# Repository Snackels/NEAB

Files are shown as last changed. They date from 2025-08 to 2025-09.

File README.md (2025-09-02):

# **Documentation for WRO Future Engineer 2025** 
by Team **YBR-NEAB**



<p align="center">
  
</p>
<p align="center">
<b>By Yothinburana School Robot Club</b>
</p>
<br><br><br><br>

### This Github repository contains:
- [About our team](#about-our-team)
- [Engineering Consideration](#engineering-consideration)
- [Chassis Design](#chassis-design)
- [Hardware Information](#hardware-information)
- [ROS 2 Humble Explanation](#ros-2-humble-explanation)
- [Raspberry Pi Program](#raspberry-pi-program)
- [Arduino Program](#arduino-program)
- [Contact Us!](#contact)

# **About our team.**
<p align="center">
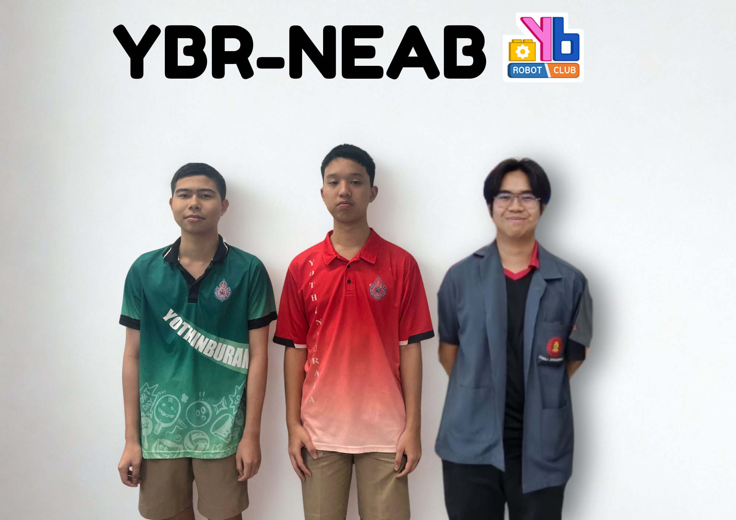
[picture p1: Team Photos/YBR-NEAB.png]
  
</p>
Our team consists of three members, each assigned a different role:

1. Vichaiwat Koonsap – I am responsible for gathering data for our team members and taking detailed notes, which are then compiled into this documentation. I'm the on the middle.
2. Norrapat Kesthong – Norrapat is responsible for designing and building our robot. He's on the right side.
3. Vorawet Narkglom – Vorawet is the programmer who coded the robot. He stands on the left side.

# **Engineering Consideration.**

During the design process of our robot, we faced several engineering challenges, particularly in translating real-world measurements into our 3D modeling software. After printing, we frequently encountered issues with small features—for example, a M3 screw thread could not be printed accurately caused by 3d printer's nozzle size, resulting in undersized holes. This showed the importance of accounting for 3D printer limitations during the design stage. Paying close attention to these details helps minimize unnecessary redesigns and reprints.

Another key learning was the importance of incorporating a differential system. At first, we placed gears of equal size next to each other, but this setup proved ineffective. By integrating a differential, the wheels were able to rotate at different speeds—an essential factor for smooth turning and overall robot performance.

The robot chassis was modeled in Fusion 360 and manufactured using FDM 3D printing. This approach provided durability, lightweight construction, and effective protection for the onboard hardware. The design was fully customized by our mechanic to meet the specific needs of our robot.

# Chassis Design
## 3D Printer and Filament
### Bambu Lab P1S Combo
<p align="center">
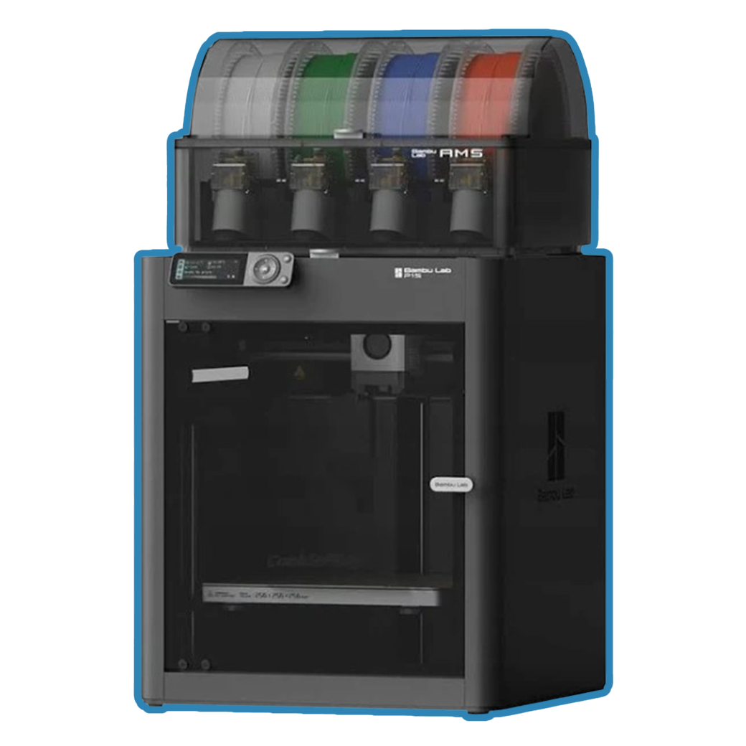
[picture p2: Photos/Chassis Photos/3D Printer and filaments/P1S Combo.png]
  
</p>
This is our 3D printer, which we use to produce both prototypes and the final robot chassis. It is capable of high-speed printing without compromising quality or risking failure. The printer features a fully enclosed chamber, allowing safe printing of high-temperature or hazardous materials such as ABS and ASA. It is one of Bambu Lab’s best-selling models.

Additionally, it comes with an Automated Material System (AMS), enabling the printer to handle up to four different materials—whether the same or different types of plastic. The AMS also includes an Auto Reload function, allowing us to print overnight without worrying about filament running out.
#### Specification
| Feature | Details |
|---|---|
| **Model** | P1S Combo |
| **Build Volume** | 256 × 256 × 256 mm³ |
| **Print Speed** | Up to 500 mm/s |
| **Acceleration** | Up to 20,000 mm/s² |
| **Extruder Type** | Direct Drive |
| **Nozzle Type** | Stainless Steel (upgradeable to hardened steel) |
| **Hotend Max Temp** | 280°C (supports high-temp filaments with upgraded nozzle) |
| **Heatbed Max Temp** | 100°C |
| **Enclosure** | Fully enclosed with carbon filter and fans |
| **Cooling System** | Auxiliary part cooling fan, chamber regulator fan, control board fan |
| **AMS Compatibility** | Yes (supports up to 16-color multi-material printing) |
| **Connectivity** | Wi-Fi, USB, Bambu-Bus |
| **Display** | 2.7-inch 192×64 screen |
| **Software** | Bambu Studio (supports Cura, PrusaSlicer, SuperSlicer) |
| **Camera** | Built-in for remote monitoring and time-lapse |
| **Dimensions (WxDxH)** | 389 × 389 × 458 mm³ |
| **Weight** | 9.5 kg |
| **Power Input** | 100–240 VAC, 50/60 Hz |
| **Max Power Consumption** | 1000 W @ 220V, 350 W @ 110V |

---

### Polylactic Acid or PLA 
<p align="center">
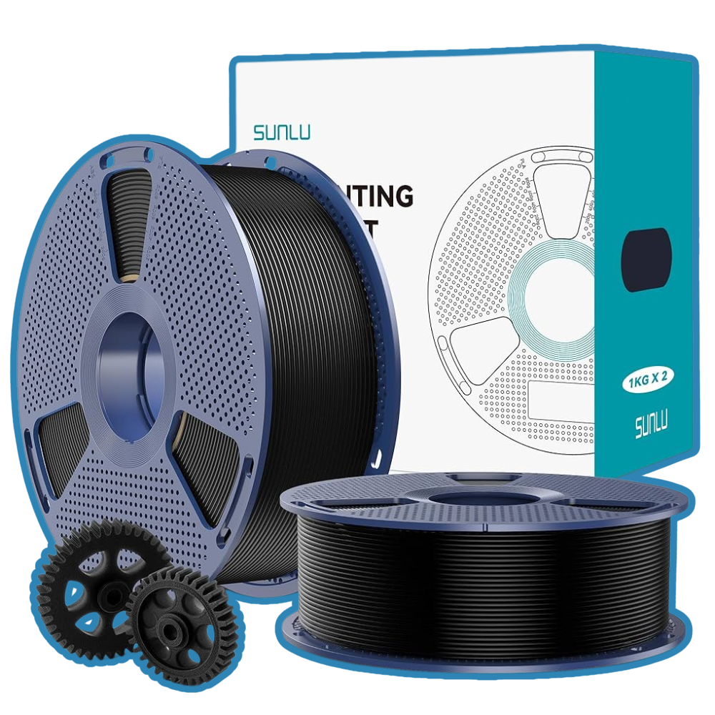
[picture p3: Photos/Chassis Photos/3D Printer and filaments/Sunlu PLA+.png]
  
</p>
PLA is the most common filament used in 3D printing. It is easy to print, produces minimal stringing, and requires relatively low printing temperatures. However, it also has some drawbacks: it cannot withstand high heat and is more brittle compared to other materials. Because of this, we use PLA for thin parts that need to remain lightweight while still providing support without bending.

For our robot, we selected **Sunlu PLA+ 2.0**, an enhanced version of standard PLA. This material is stronger, lighter, and more flexible, giving us the benefits of PLA while improving durability and performance.

### Polyethylene Terephthalate Glycol or PETG
<p align="center">
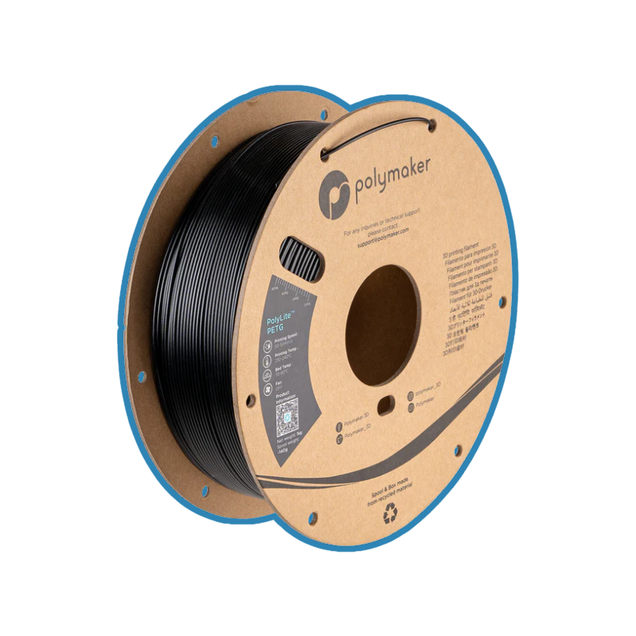
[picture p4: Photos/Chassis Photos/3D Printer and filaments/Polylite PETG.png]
  
</p> 
PETG is another popular 3D printing filament, valued for its flexibility, strength, chemical resistance, and ability to withstand higher temperatures than PLA. Its main drawbacks are increased stringing and a slightly rougher surface finish.

Because PETG is highly impact-resistant, we use it for components that are more likely to experience collisions, ensuring the robot remains intact even after repeated impacts.

For our robot, we selected **Polymaker PolyLite PETG**. Polymaker is a trusted brand known for its consistency and reliability, with minimal defects. This PETG is particularly user-friendly, offering printability close to that of PLA while maintaining the toughness needed for demanding parts.

---

## Printed Robot Chassis
[All the 3D printable models can be found here](https://github.com/Snackels/NEAB/tree/main/3D%20models).
### Lower Base
<p align="center">
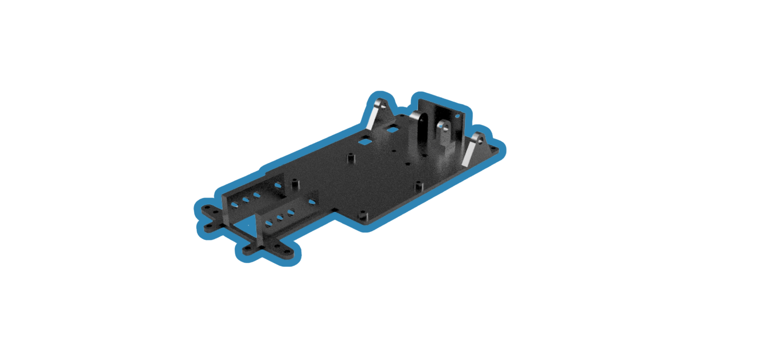
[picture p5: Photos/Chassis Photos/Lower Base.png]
  
</p>
The lower base serves as the foundation of our robot, supporting nearly all essential components: the controller, motors, steering servo, light sensors, buck converter, and differential.  
 
When designing this part, precise measurements were critical to ensure a proper fit for each component. In our robot, we uses a **LEGO TECHNIC** parts like axle, differential, and gear to ensure that those part would not break during our sessions.

To secure the LEGO axle, we designed support poles at the back of the base to hold it firmly in place. With this design, it allows the robot to reach it's full potential.

### Upper Base
<p align="center">
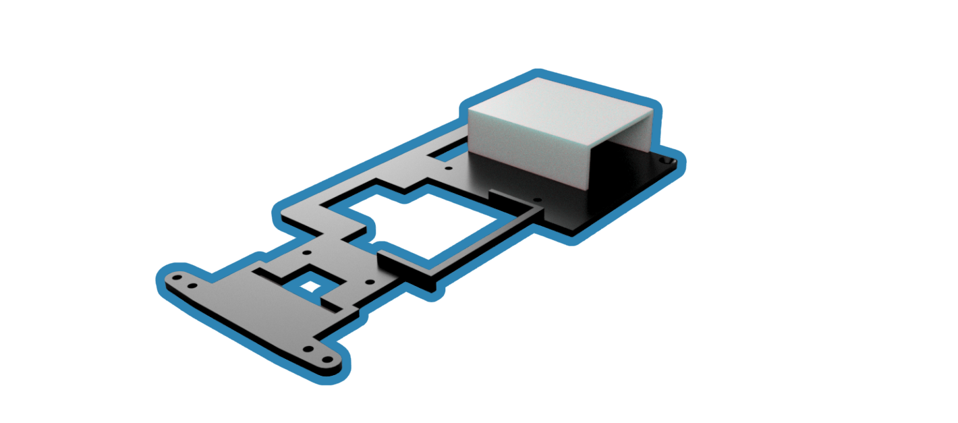
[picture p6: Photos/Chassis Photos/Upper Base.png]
  
</p>
The upper base is positioned 3 cm above the lower base and is designed to hold the remaining components while providing additional stability to the robot.  

To ensure a clean and seamless build, we applied the **counterbore technique** so that screws do not interfere with the lower section. This approach allowed us to hide the screws neatly, giving the chassis a screwless appearance.  

Additionally, the upper base includes a **battery slot** at the back, ensuring secure placement and easy accessibility during operation.

### Arduino Nano Riser
<p align="center">
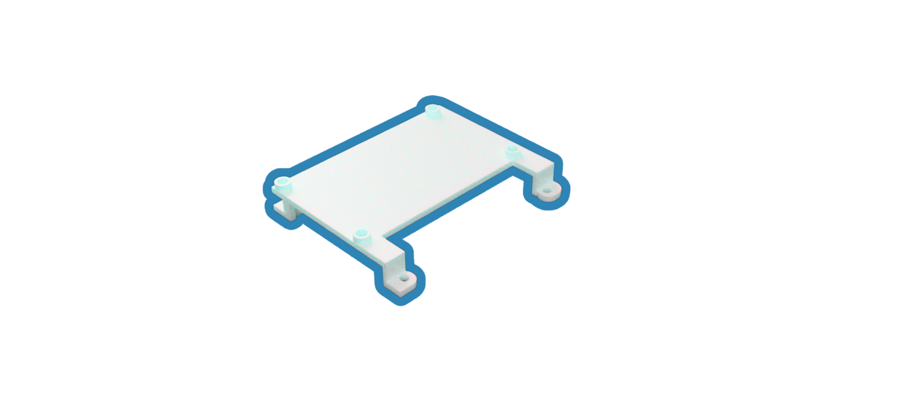
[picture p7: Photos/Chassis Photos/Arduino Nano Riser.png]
  
</p>
Since we are using the Arduino Nano, we needed to find an ideal place to mount it. The perfect location is right on top of the Raspberry Pi, allowing both boards to stay compact and organized. To achieve this, we designed the setup to use the same M2.5 screws that secure the Raspberry Pi. We also carefully accounted for the position of the GPIO pins and all necessary wiring, ensuring that everything fits neatly without interfering with connections.

### LiDAR Holder
<p align="center">
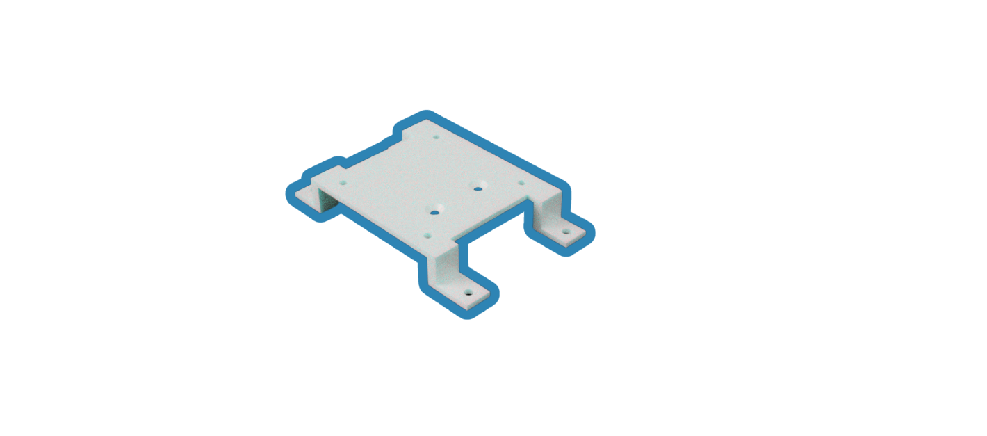
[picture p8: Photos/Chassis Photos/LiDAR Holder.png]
  
</p>
The LiDAR holder is mounted on top of the upper base to keep the LiDAR elevated above other components. This prevents the sensor from mistakenly detecting parts of the robot itself.  

The holder also included a **slot for the gyro sensor**, positioned directly beneath the LiDAR. This compact arrangement minimizes the overall robot size while ensuring that the LiDAR remains within the **10 cm height limit** to avoid detecting over the wall.  

### Camera mount
<p align="center">
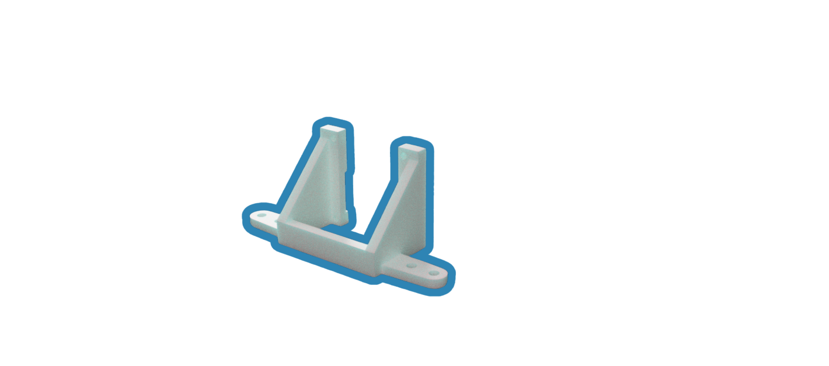
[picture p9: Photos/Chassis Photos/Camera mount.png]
  
</p>
This component serves as a **stand for the camera** and includes protective covers for both the front and top.  

The design serves two key purposes:  
1. **Protection** – In case of collisions with walls, the front cover acts as a guard to protect the camera lens from damage.  
2. **Vision Control** – The top cover blocks external light and distractions, ensuring the camera only captures the track area.  

This combination enhances both the durability and reliability of the vision system during sessions.  

### Motor Bracket
<p align="center">
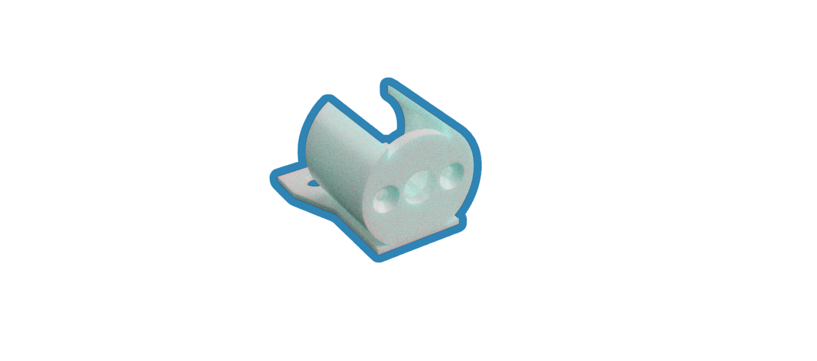
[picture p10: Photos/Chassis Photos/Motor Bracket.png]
  
</p>
It holds the motor with the lower base. This design offer us a small, effective, and strong bracket. With 3 screw holes for attaching it to the base and 2 screw holes for attaching it to motor. This part also uses the Counterbore technique.

### Gear Adapter
<p align="center">
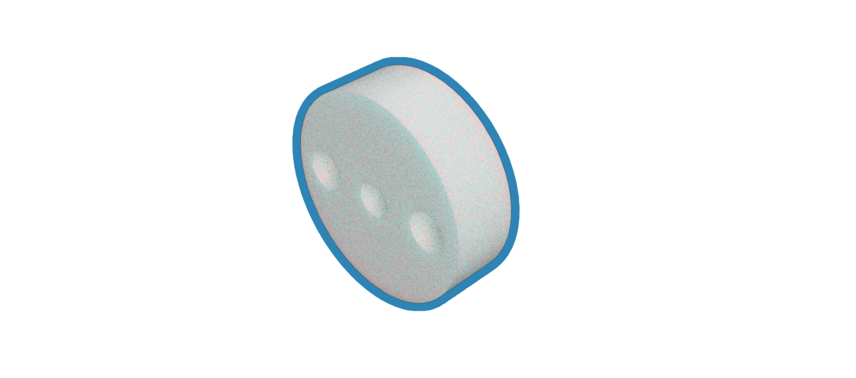
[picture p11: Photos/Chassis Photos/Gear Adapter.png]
  
</p>
The gear we used was from **LEGO Technic**. Meaning that we can't attach it directly to the motor. We designed this part to place it on motor's rotating axle. Then, we added two LEGO pins to attach it to the gear.

### Step-Down Case
<p align="center">
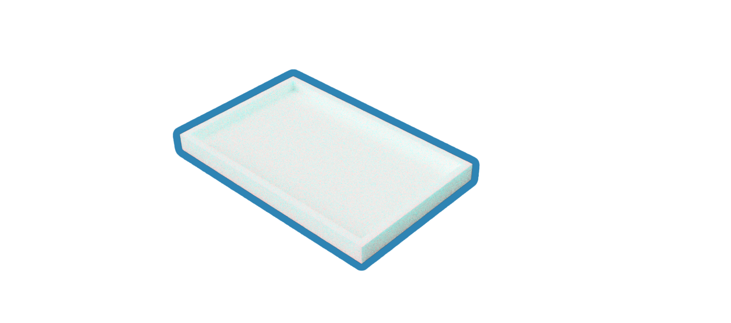
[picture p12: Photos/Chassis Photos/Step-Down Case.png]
  
</p>
The buck converter comes with a lot of pin under it. This was caused by soldering. This case was made to make sure that the bottom stays flat and avoid current leakage.

### Steering Module
<p align="center">
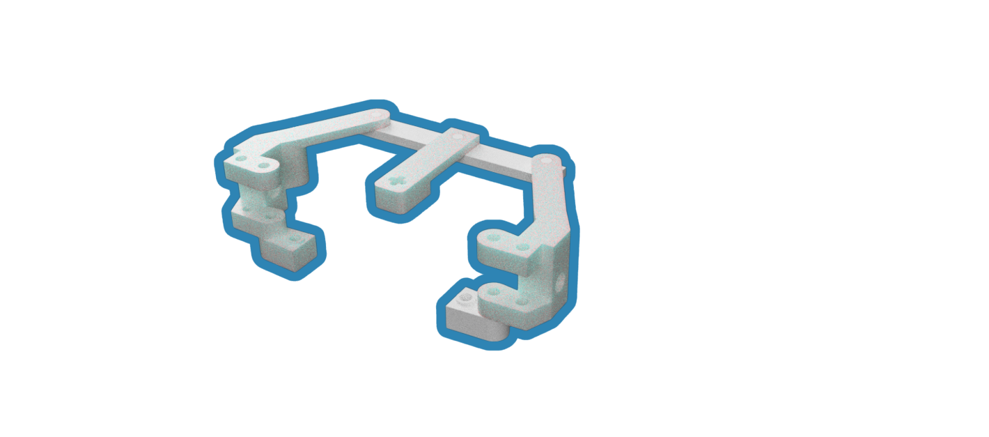
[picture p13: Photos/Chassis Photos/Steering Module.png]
  
</p>
It consists of three main components: the servo link, main connector, and wheel bracket. When our mechanic designed this part, careful consideration was given to the steering angle. We applied the Ackermann Steering Principle, a system developed to achieve tighter and more efficient turns. With this method, the inner wheel turns at a sharper angle than the outer wheel—similar to the steering system used in Formula 1 cars. We also ensured that, during turns, the wheels would not collide with the robot’s body.

---

## LEGO Technic Parts
### Differential
<p align="center">
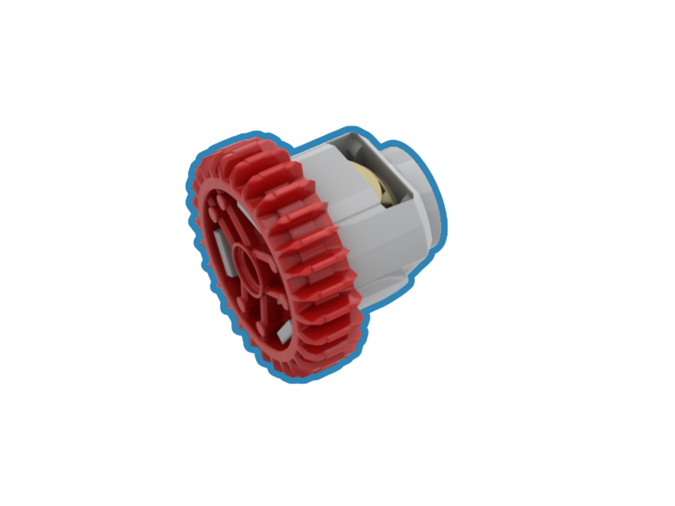
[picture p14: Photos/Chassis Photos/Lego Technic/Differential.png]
  
</p>
This differential includes a 28-tooth double bevel gear, identical to the one used with our motor. Inside, it contains five small gears that allow the opposite wheel to rotate freely. This mechanism ensures that both wheels rotate at the correct speed, even when the robot is turning.

### Gear
<p align="center">
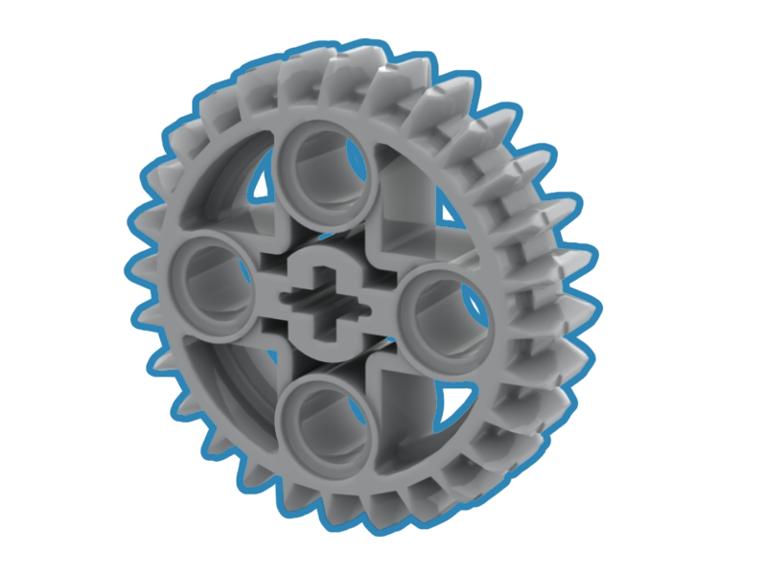
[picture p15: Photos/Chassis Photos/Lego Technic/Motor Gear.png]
  
</p>
We selected a 28-tooth double bevel gear to prevent the robot from losing speed or torque. It is made of ABS plastic, providing durability, and matches the size of the differential.

### Wheel: 43.2 * 22
<p align="center">
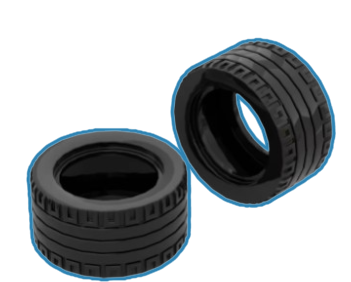
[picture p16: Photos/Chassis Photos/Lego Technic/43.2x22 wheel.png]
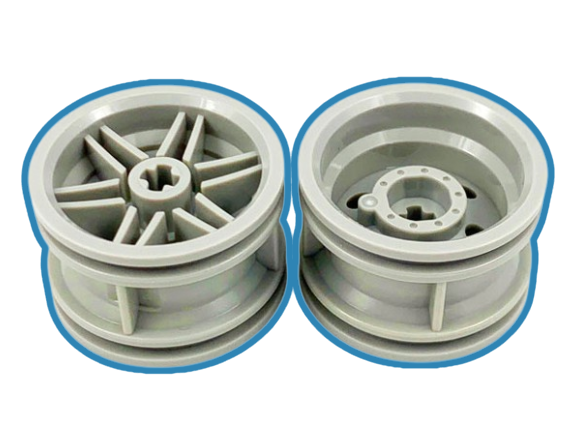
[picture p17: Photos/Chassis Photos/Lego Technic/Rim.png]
  
</p>
The wheel is a crucial component of our robot and comes in various sizes and shapes. We selected this size for its ability to maintain grip on the surface during high-speed turns. Its 43.2 diameter also makes the robot easy to control.

### Pin
<p align="center">
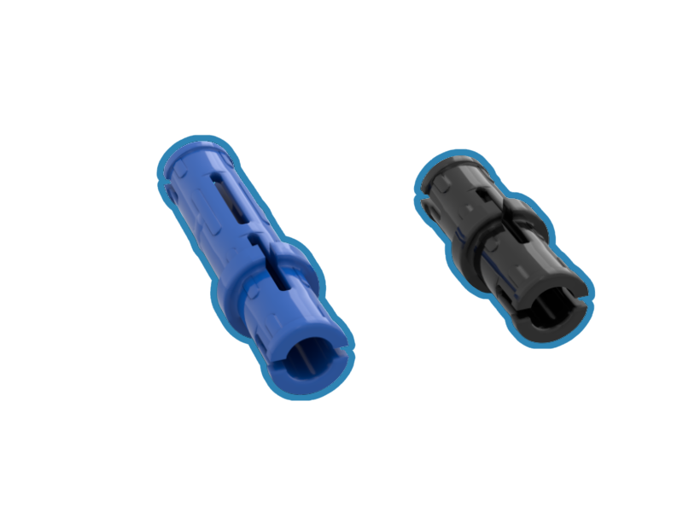
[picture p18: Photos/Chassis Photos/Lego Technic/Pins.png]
  
</p>
These pins are used to secure the servo to the robot. They act as a lock, ensuring the servo stays firmly in place.

### Axle
<p align="center">
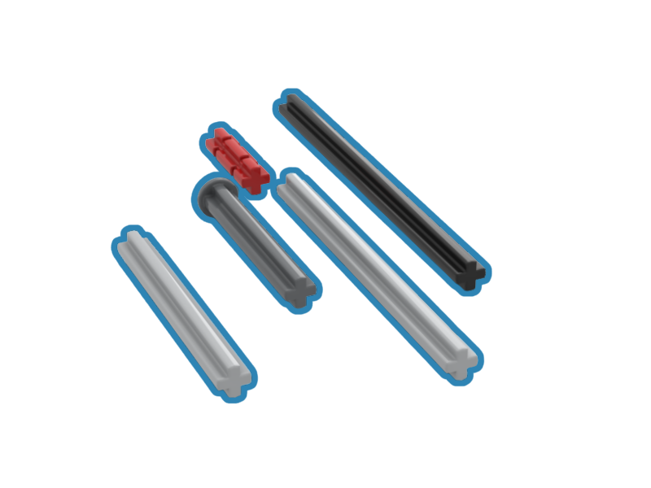
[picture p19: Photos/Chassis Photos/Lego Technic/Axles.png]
  
</p>
Axles connect the wheels to the robot. We designed a 5.1 mm hole for the axle, allowing it to sit securely while still rotating freely.

### Half Bush
<p align="center">
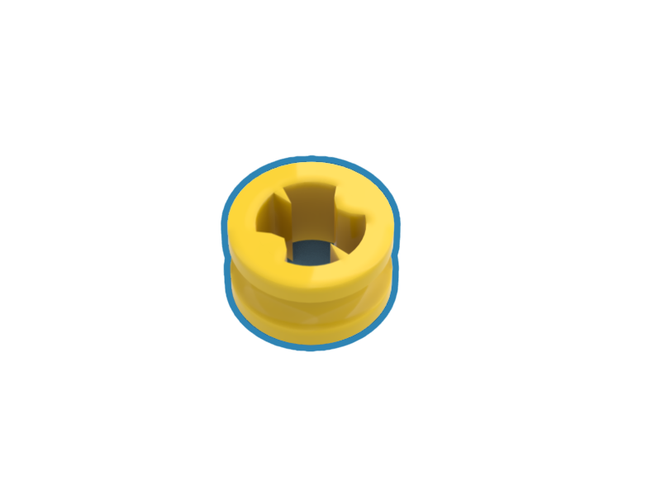
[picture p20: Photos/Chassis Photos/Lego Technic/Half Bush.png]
  
</p>
This component creates space between the wheel and the robot, ensuring that the wheels can rotate freely without being obstructed during operation.

---

## Additional
### Screws
Screws come in various sizes. We designed our robot primarily around M3 screws, as they are the most common in robotics. In some cases, such as mounting the Raspberry Pi or LiDAR, M2.5 screws are required. For our build, we mainly use countersunk screws. To accommodate them, we chamfered the M3 screw holes by 1.8 mm, creating the perfect countersunk fit that allows the screws to sit flush and remain neatly hidden.

<p align="center">
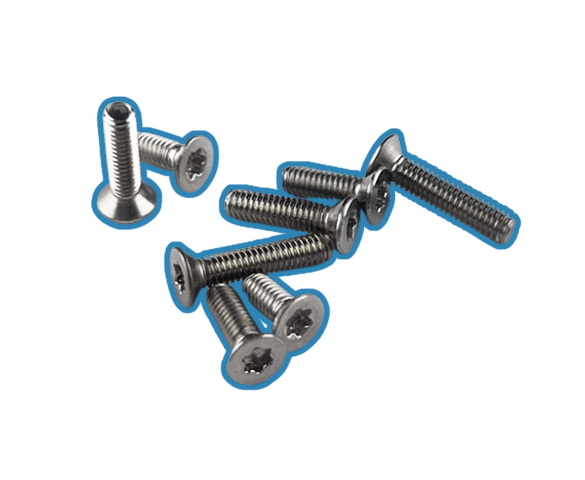
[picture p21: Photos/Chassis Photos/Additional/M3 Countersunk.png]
  
  <br>
  <b>M3 Countersunk Screws</b>
</p>

<p align="center">
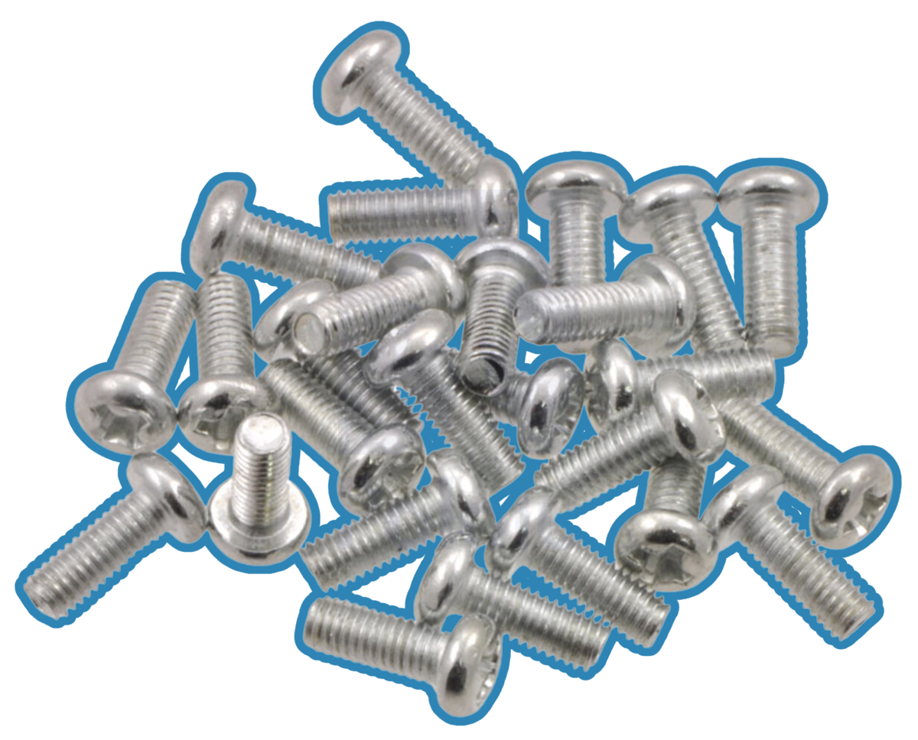
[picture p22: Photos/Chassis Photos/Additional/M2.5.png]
  
  <br>
  <b>M2.5 Screws</b>
</p>

---

### PCB Support Post
<p align="center">
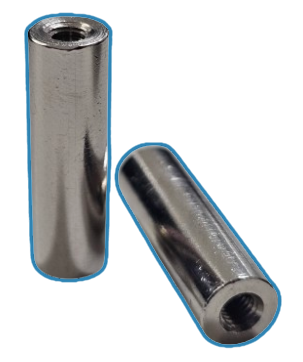
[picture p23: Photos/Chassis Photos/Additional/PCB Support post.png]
  
</p>
The support posts connect the first and second floors of the robot. They enhance stability, ensuring that the LiDAR and camera remain steady during operation.

## Design References
### Counterbore Technique
<p align="center">
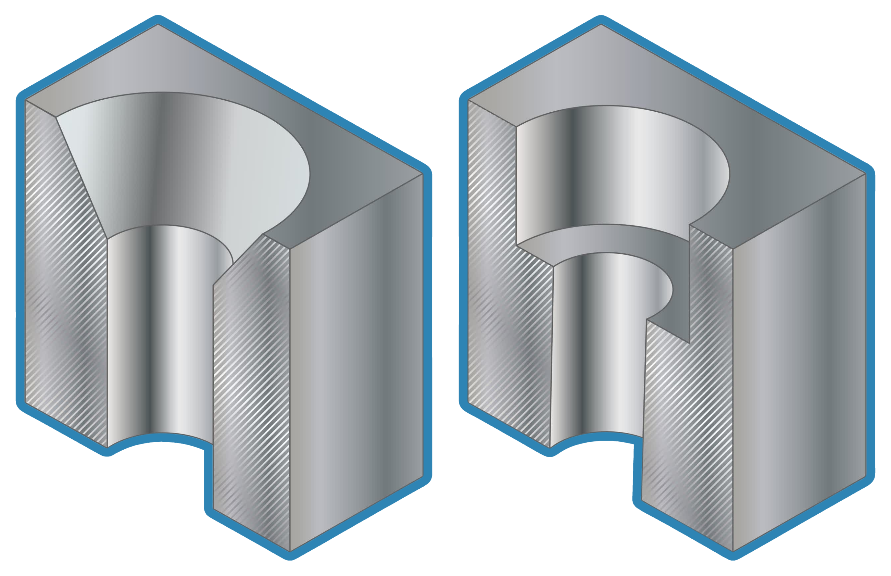
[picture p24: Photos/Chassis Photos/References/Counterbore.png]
  
</p>
Counterbore and countersunk are two techniques used to make screws sit flush with a surface. A countersunk hole has an angled top, allowing cone-shaped screws to fit neatly inside and create a smooth finish, while a counterbore hole has a flat, widened top so cylindrical screw heads can sit below the surface. In our robot, we use these methods to merge the screw into the structure by chamfering 1.8 mm into the screw hole or creating a 4 mm wide hole with a 2 mm depth. This not only saves space but also gives the robot a cleaner and more professional look.

### Ackerman Steering
<p align="center">
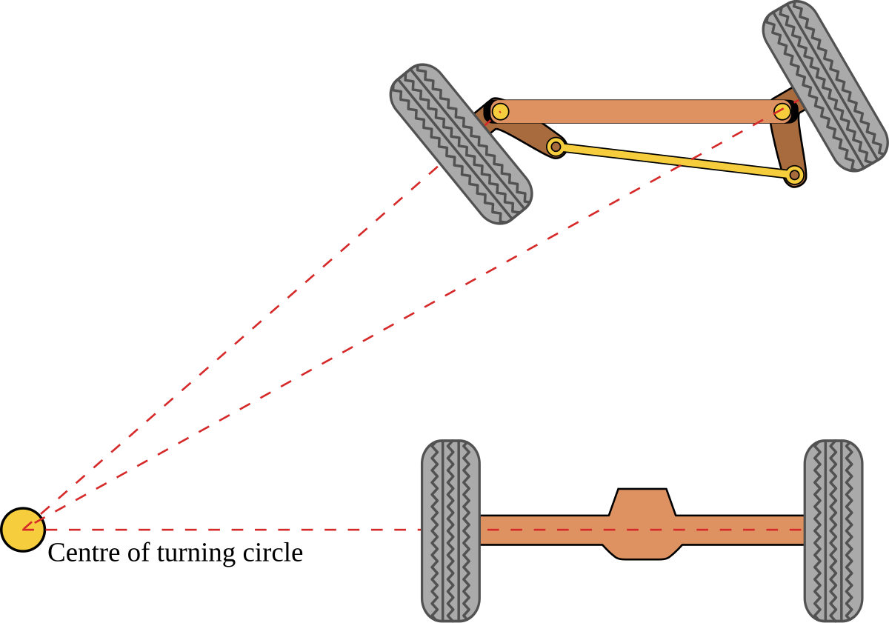
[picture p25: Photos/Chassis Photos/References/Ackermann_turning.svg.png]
  
</p>
Ackermann steering is a method where the inner wheel turns sharper than the outer wheel when the robot turns. This matches the natural path of the wheels, preventing them from sliding against the ground. It makes the robot easier to control, gives it a tighter turning radius, and reduces friction—just like in real cars and F1 racing.

## Printing Process
To print this robot, we first use a slicer to generate the ****G-code** for the 3D printer. In our case, we use **Bambu Studio**. A slicer lets us set up a **print profile**, which defines whether the part will be strong, lightweight, or have a smooth surface. Once the profile is set, we check for **overhangs** — parts of the model that **“float”** without support. While printers can handle small overhangs, larger ones require supports. Supports are temporary structures that hold the object during printing and can be removed afterward. There are two main types: **normal supports** and **tree supports**, with tree supports being the most popular because they use less filament and print faster. After preparing everything, we start the print.

Here’s a timelapse of the printing process for some of our parts:
| Accessories Timelapse | Lower Chassis Timelapse |
|---|---|
|  |  |

### Post-Printing Process
After a print is complete, some defects may appear. The most common one is **stringing**, which can be removed by applying gentle heat with a lighter or heat gun. Stringing is usually caused by **moist filament**, especially with PETG. To prevent this, use a filament dryer to remove excess moisture.

Another common issue is an **uneven or rough surface**. This can result from blobbing, an unlevel print bed, or low-quality filament. The surface can be improved by sanding with fine sandpaper.  

Lastly, there’s **support and brim removal**. Supports are needed for complex prints, while brims improve bed adhesion. However, they often leave rough edges, which can be cleaned up with the right tools.

---

#### Essential 3D Printing Tools

- **Plier**  
<p align="center">
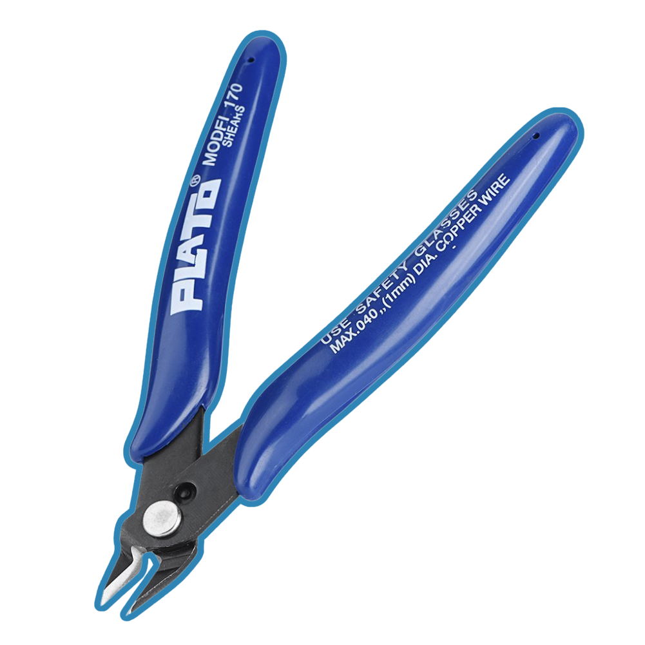
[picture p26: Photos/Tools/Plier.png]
  
</p>  
Used for removing supports and trimming away unwanted parts of the print.

---

- **Glue Stick**  
<p align="center">
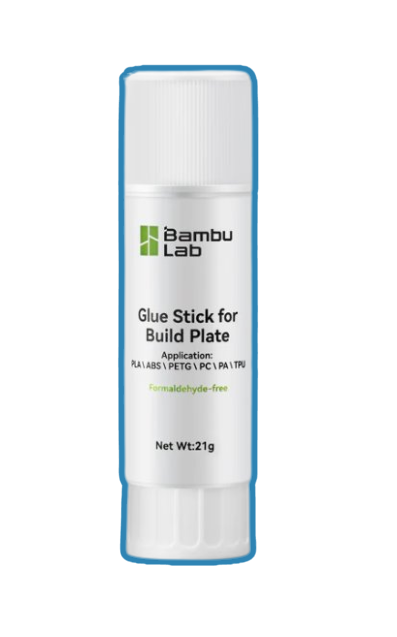
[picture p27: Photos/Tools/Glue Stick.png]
  
</p>  
Applied to the print bed as a **release agent**—not to increase stickiness, but to make parts easier to remove once printing is finished.

---

- **Lighter or Heat Gun**  
<p align="center">
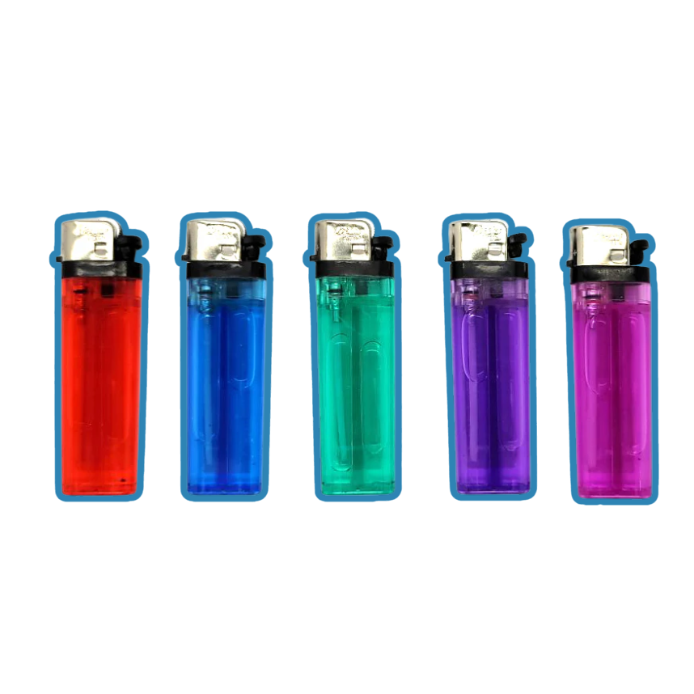
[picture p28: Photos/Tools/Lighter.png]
  
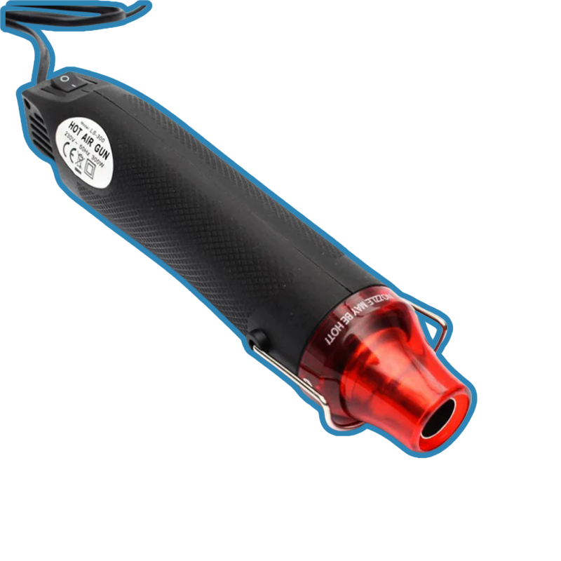
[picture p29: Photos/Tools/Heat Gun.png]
  
</p>

<p align="center">
  Lighter &nbsp;&nbsp;&nbsp;&nbsp;|&nbsp;&nbsp;&nbsp;&nbsp; Heat Gun
</p>

Essential for removing stringing. In some cases, heat can also soften the plastic, making it easier to reshape.

---

- **Deburring Tool**  
<p align="center">
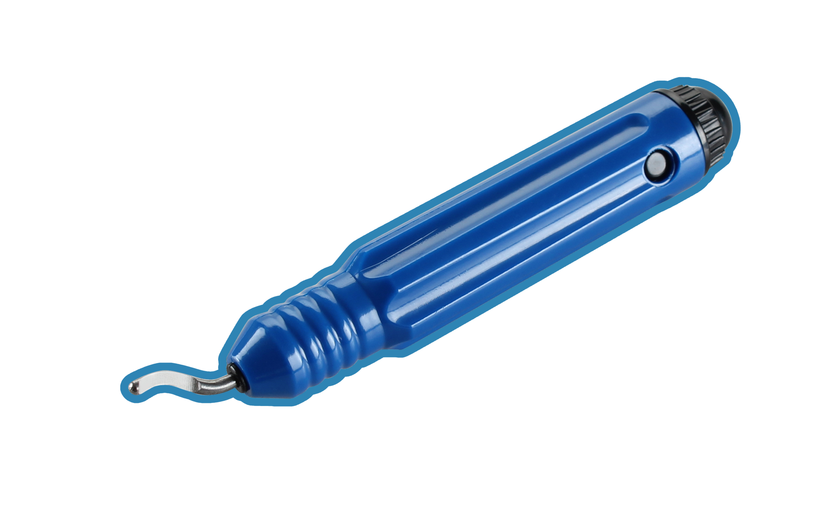
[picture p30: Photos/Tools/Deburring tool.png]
  
</p>  
Designed to remove brims. Brims help parts stick to the bed, but sometimes they bond too well, leaving rough edges. A deburring tool makes cleanup much easier.

---

- **Sandpaper**  
<p align="center">
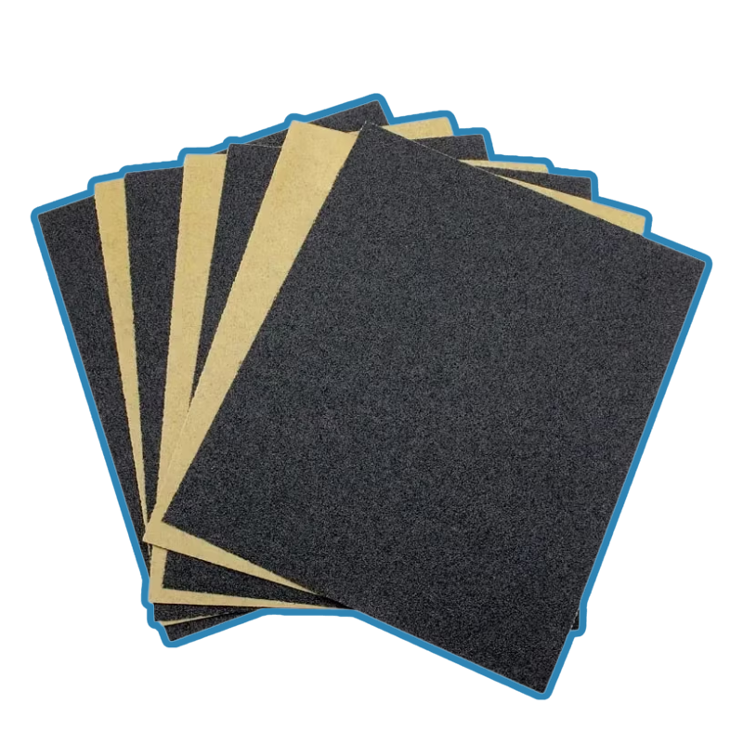
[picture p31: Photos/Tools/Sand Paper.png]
  
</p>  
Used for smoothing surfaces. Simply rub it over the rough areas for a few minutes to achieve a cleaner, polished finish.

## Full Chassis Assembly
This is what our robot looks like with all the chassis part combined. 
<p align="center">
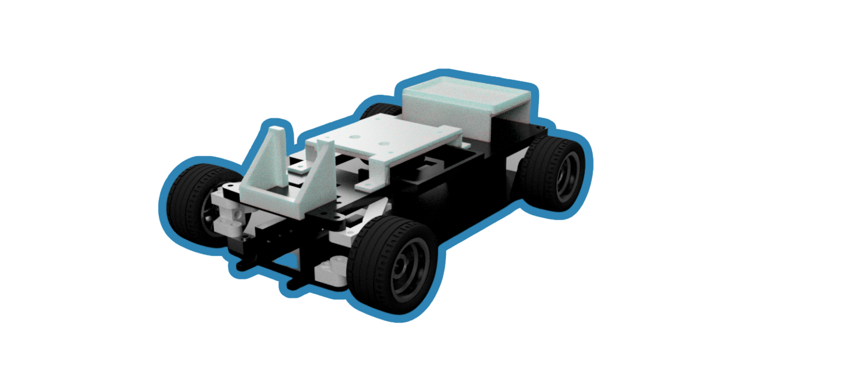
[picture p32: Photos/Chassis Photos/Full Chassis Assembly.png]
  
</p>

---

# Hardware Information
## Controller
### Main controller:  Raspberry Pi 4 Model B from Raspberry Pi
<p align="center">
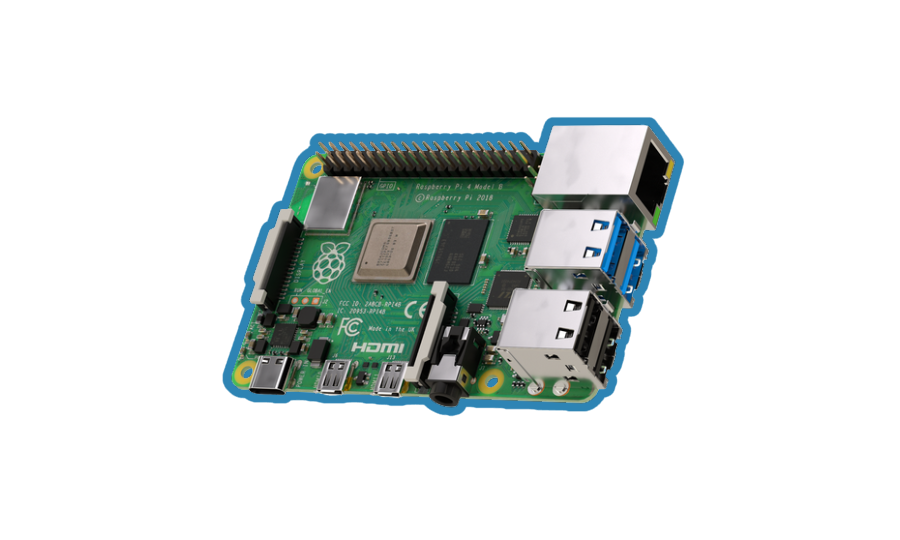
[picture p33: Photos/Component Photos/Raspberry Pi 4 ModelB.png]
  
</p>
The Raspberry Pi 4 Model B was the first component we selected, and it serves as the most crucial part of the robot, acting as the brain of the system. Without it, the robot cannot process information or make decisions. The Raspberry Pi is widely used as a controller due to its versatility and accessibility, functioning like a mini computer with 4 USB ports, 40 GPIO pins, and dedicated slots for a camera and monitor. It can be powered via a USB-C connector with an operating voltage of 5 volts. Since we chose ROS2 as the robot’s operating system, the Raspberry Pi 4 was the ideal choice to handle the required computation and communication tasks. And It can be connect with Wi-Fi or LAN cable for communicating with the programming computer.

#### Specification
| Feature | Details |
|---|---|
| **Processor** | Broadcom BCM2711, Quad core Cortex-A72 (ARM v8) 64-bit SoC @ 1.8GHz |
| **Memory Options** | 1GB, 2GB, 4GB or 8GB LPDDR4-3200 SDRAM |
| **Wireless** | 2.4 GHz and 5.0 GHz IEEE 802.11ac, Bluetooth 5.0, BLE |
| **Ethernet** | Gigabit Ethernet |
| **USB Ports** | 2 × USB 3.0, 2 × USB 2.0 |
| **GPIO** | 40-pin header (fully backwards compatible) |
| **Display Output** | 2 × micro-HDMI® (up to 4kp60), 2-lane MIPI DSI |
| **Camera Interface** | 2-lane MIPI CSI port |
| **Audio/Video** | 4-pole stereo audio and composite video port |
| **Video Support** | H.265 (4kp60 decode), H.264 (1080p60 decode, 1080p30 encode) |
| **Graphics** | OpenGL ES 3.1, Vulkan 1.0 |
| **Storage** | Micro-SD card slot (OS and data storage) |
| **Power Input** | 5V DC via USB-C (min 3A), 5V DC via GPIO (min 3A), Power over Ethernet (PoE with HAT) |
| **Operating Temperature** | 0 – 50 °C ambient |

---

### Extension Board: Arduino Nano from Princebot
<p align="center">
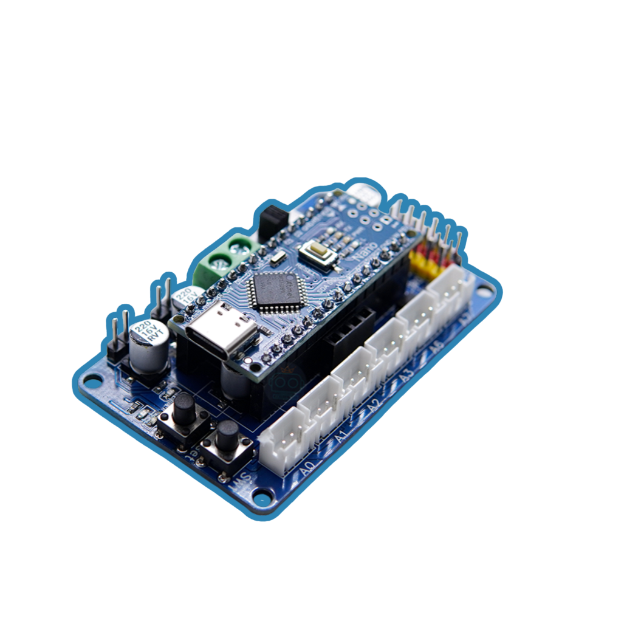
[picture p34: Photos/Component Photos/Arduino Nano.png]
  
</p>
Using a Raspberry Pi comes with some limitations. Its GPIO pins only provide digital signals, meaning it cannot directly control motors or servos, and it also lacks built-in support for analog readings. To solve this, we use an extension board. The Arduino Nano is a small, fast, and flexible microcontroller, making it an ideal choice. By pairing the Nano with a custom PCB, we can easily drive motors, control servos, and read data from analog sensors. The PCB supports up to 10 volts of battery input, which makes it the perfect fit for our robot components.

#### Specification
| Feature | Details |
|---|---|
| **Processor** | Atmega328 (Arduino Nano) |
| **Input Voltage** | 6–10 V (with reverse polarity protection) |
| **Motor Driver** | 2 × modules (6–10 V, 1.5 A each) |
| **Sensor Ports** | 6 × Analog (JST connectors) |
| **Servo Ports** | 6 × Digital (servo compatible) |
| **Buzzer** | 1 × Speaker |
| **Switches** | 1 × Switch (D12), 1 × Reset switch |
| **Dimensions** | 64 mm (W) × 45 mm (H) |

---

## Sensors and visibility
### LiDAR: RPLIDAR C1 from SLAMTEC
<p align="center">
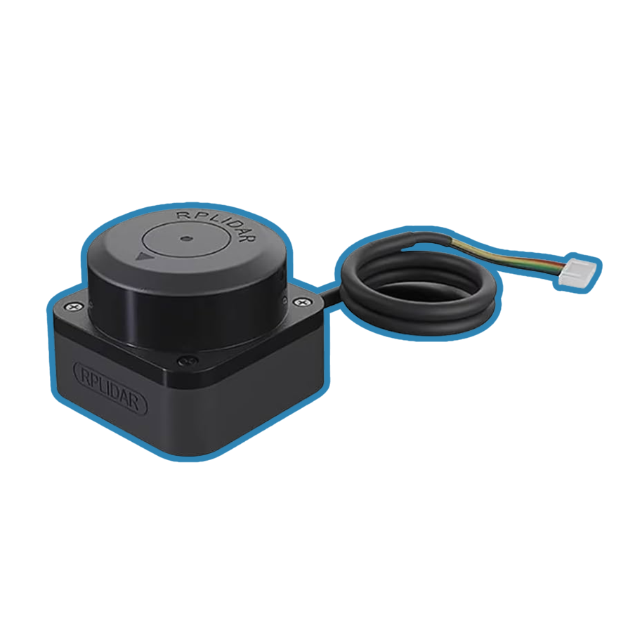
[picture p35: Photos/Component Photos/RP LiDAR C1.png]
  
</p>
This is a LiDAR, a device that emitted light toward the surface and then measure the time it take to bounce back. Most of the car uses it for parking. This part plays a crucial role in this competition, by measuring the distance between the inner and outer wall then divide by 2 so that the robot would stay in the perfect middle. And it also plays a significant role in parking sequence due to it's ability to view 360 degree. We can connect the LiDAR with the USB port on Raspberry Pi, making it very user friendly.

#### Specification
| Feature | Details |
|---|---|
| **Distance Range** | White object: 0.05–12 m (70% reflectivity)<br>Black object: 0.05–6 m (10% reflectivity) |
| **Sample Rate** | 5 kHz |
| **Scanning Frequency** | 8–12 Hz (10 Hz typical) |
| **Angular Resolution** | 0.72° (typical) |
| **Scan Field Flatness** | 0°–1.5° |
| **Communication Interface**  | TTL UART |
| **Communication Speed** | 460800 baud |
| **Accuracy** | ±30 mm |
| **Resolution** | 15 mm |
| **Degree of Protection** | IP54 |
| **Ambient Light Limit** | 40,000 lux |
| **Weight** | 110 g |
| **Working Temperature** | -10 °C to +40 °C |
| **Storage Temperature** | -20 °C to +60 °C |

---

### Camera: HBV-1716WA
<p align="center">
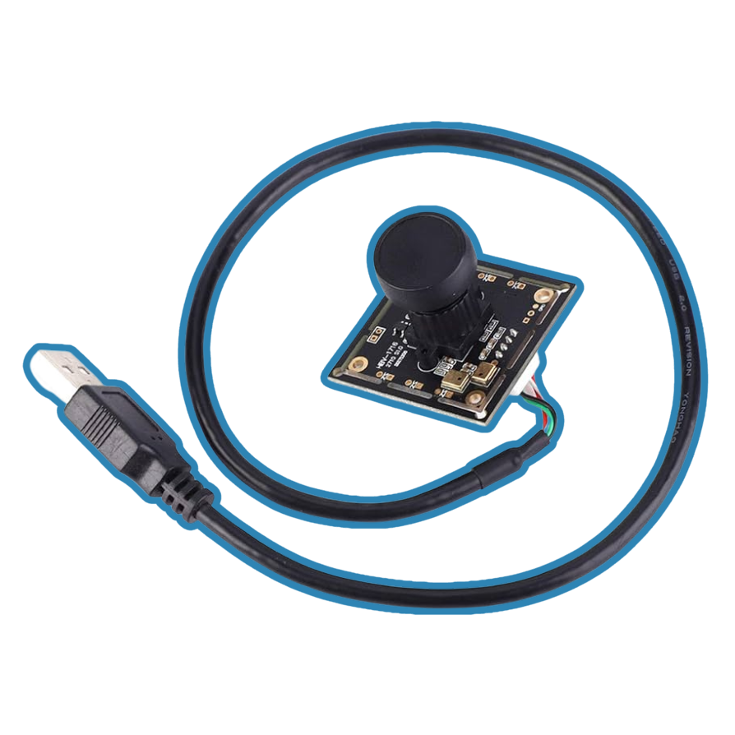
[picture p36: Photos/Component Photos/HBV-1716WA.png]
  
</p>
This component is very important for avoiding obstacle. It can detect red and green obstacle from distance to avoid crashing into it. It can co-operate with the LiDAR to ensure the maximum efficiency when the robot turns to avoid the block. This camera doesn't have it's own micro-controller meaning that it can achive it's full **frame per sec** performance. And it can also be connect to Raspberry Pi through USB port.

#### Specification
| Feature | Details |
|---|---|
| **Model** | HBV-1716WA |
| **Highest Resolution** | 1920 × 1080 |
| **Field of View** | 140° |
| **Chip** | OV2710 (1/2.7") |
| **Frame Per Second** | 30 FPS
| **Weight** | Approx. 32 g / 1.1 oz |
| **Outer Size** | Approx. 38 × 38 × 25 mm / 1.5 × 1.5 × 1.0 in |
| **Inner Size** | Approx. 32 × 32 × 25 mm / 1.3 × 1.3 × 1.0 in |

---

### Gyro Sensor: SEN-0253 from DFRobot
<p align="center">
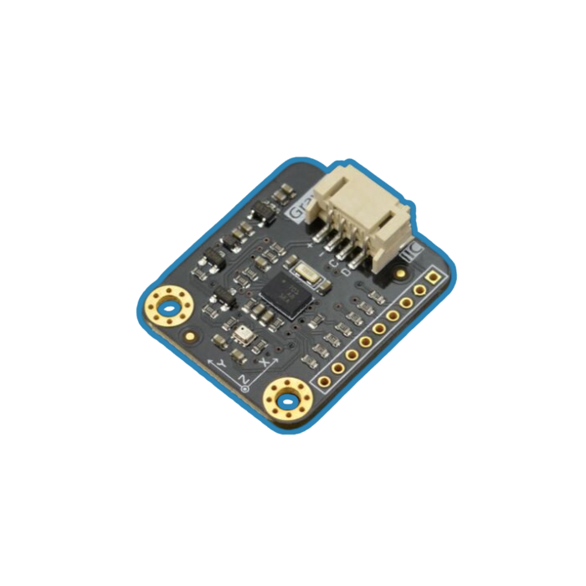
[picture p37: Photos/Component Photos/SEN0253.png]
  
</p>
Gyro sensor is a component that enables a robot to determine its orientation and turn in the appropriate direction. The gyro sensors detect 3 axis: yaw, pitch, and roll. We chose this gyro sensor specifically because of how effective it is. It collaborate with LiDAR and camera to ensure that the robot would not steer of it's course when it's turning to avoid the obstacle. And it also helps when the robot initiate the parking. It helps the robot make sure that it is turning toward the right direction. The gyro uses I2C wiring. The I2C features 4 different wire: SDA, SCL, 5 volts, and Ground. The wires go onto the GPIO pins on Raspberry Pi.

#### Specification
| Feature | Details |
|---|---|
| **Operating Voltage** | 3.3 V – 5 V DC |
| **Operating Current** | 5 mA |
| **Interface** | Gravity-I2C |
| **Operating Temperature** | -40 ~ +80 °C |
| **Product Dimension** | 32 × 27 mm / 1.26 × 1.06” |

##### BNO055 Accelerometer
| Feature | Details |
|---|---|
| **Acceleration Ranges** | ±2 g / ±4 g / ±8 g / ±16 g |
| **Low-pass Filter Bandwidth** | 1 kHz ~ <8 Hz |
| **Operation Modes** | Normal, Suspend, Low Power, Standby, Deep Suspend |
| **Interrupt Control** | Motion-triggered interrupt signal |

##### BNO055 Gyroscope
| Feature | Details |
|---|---|
| **Ranges** | ±125°/s ~ 2000°/s (switchable) |
| **Low-pass Filter Bandwidth** | 523 Hz ~ 12 Hz |
| **Operation Modes** | Normal, Fast Power Up, Deep Suspend, Suspend, Advanced Power Save |
| **Interrupt Control** | Motion-triggered interrupt signal |

##### BNO055 Geomagnetic
| Feature | Details |
|---|---|
| **Magnetic Field Range** | ±1300 μT (x-, y-axis), ±2500 μT (z-axis) |
| **Magnetic Field Resolution** | ~0.3 |
| **Operating Modes** | Low Power, Regular, Enhanced Regular, High Accuracy |
| **Power Modes** | Normal, Sleep, Suspend, Force |

##### BMP280 Digital Pressure Sensor
| Feature | Details |
|---|---|
| **Pressure Range** | 300 ~ 1100 hPa |
| **Relative Accuracy** | ±0.12 hPa (~ ±1 m) |
| **Absolute Accuracy** | ±1 hPa (~ ±8.33 m) |
| **Temperature Range** | 0 °C ~ 65 °C |
| **Temperature Resolution** | 0.01 °C |

---

### Reflected Light Sensors: TC-01 from Princebot
<p align="center">
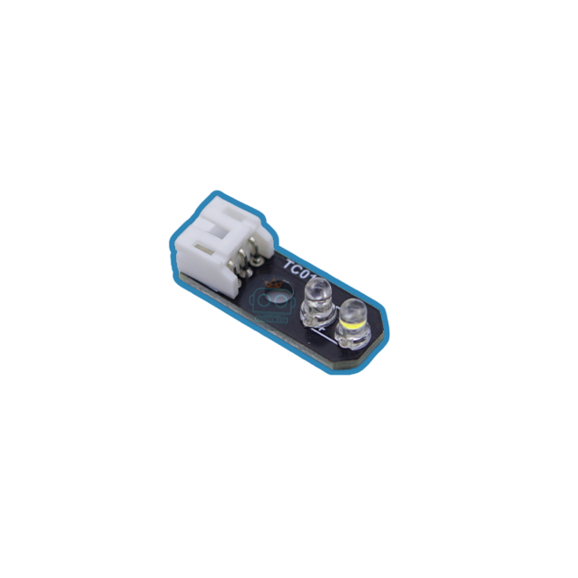
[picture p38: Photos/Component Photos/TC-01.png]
  
</p>
Reflected Light Sensors come in various color. Each color can be used for different surface color. This track has 3 different colors: red, blue, and white. We tried using a single red or blue light, but it doesn't work. So at first we come up with using 2 sensors at the same time. And in the end, we settle on using a single **White light** color. White has an ability to amazingly seperate the red, blue, and white. It's purpose is to count and detect lines. This sensor uses **JST** head as a connector. Since our extension board also uses JSTs, we can connect the sensor straight to it.

---

### Touch Sensor: ZX-Switch from INEX
<p align="center">
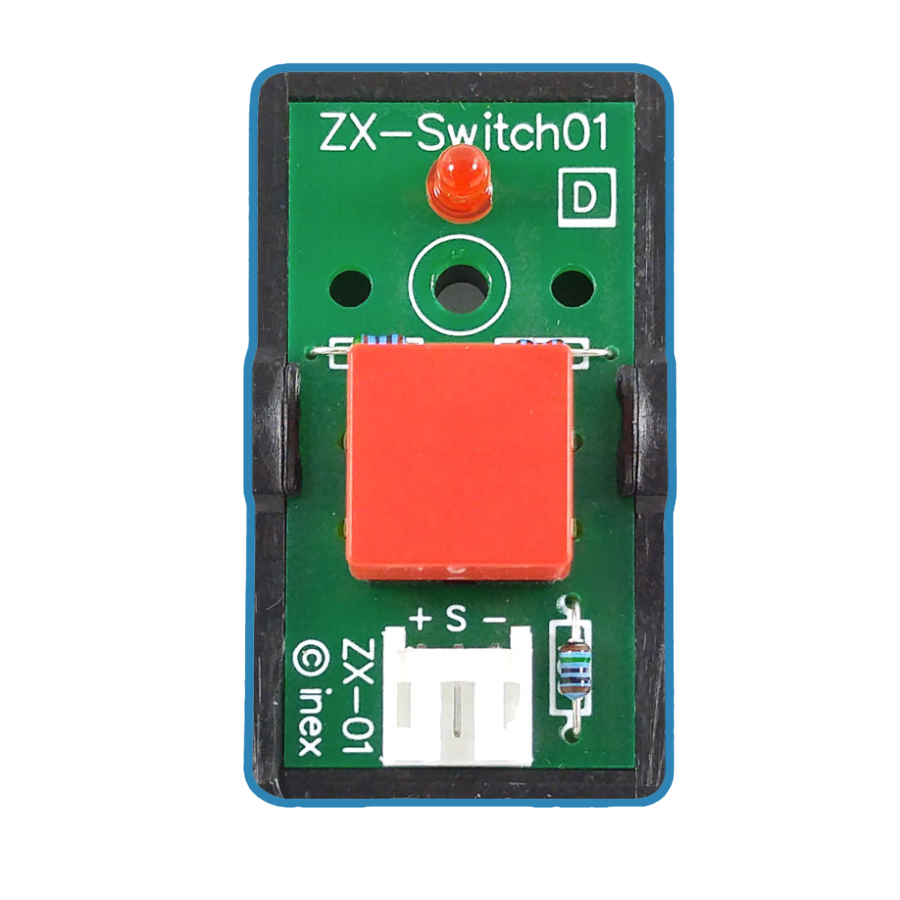
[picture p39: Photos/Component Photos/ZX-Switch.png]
  
</p>
This button gives us an easier way to start the robot. Since the controller board doesn't come with switches. So, we found this button that could be attached to the frame outside the board using bolt. It gives us the advantages, when we start the robot we can turn on the switch and then keep the robot on the ground so that it would have time to reset it's gyro and other components. Then we press the switch to start and stop the robot. This sensor required a digital reading. The input would be 0 and 1. 1 being pressed and 0 being nothing. We wired this straight into Raspberry Pi's GPIO pins.

---

## Driving and Steering
### Motor: GM25-370 from Chihai Motor
<p align="center">
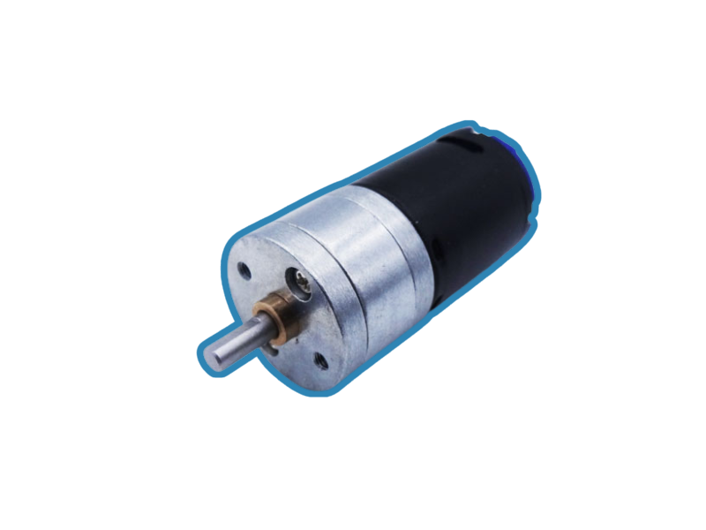
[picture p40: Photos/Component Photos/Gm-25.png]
  
</p>
This motor is usually used for a sumo robot due to it's speed and power. We then uses this with our robot because it can help us achive the speed we need to win this competition. And since our robot is very heavy due to the various components, this motor comes in real handy. We uses this motor with extension board to control the speed and the power it uses. The rotating axis is connected to a gear which then transfer the spinning to a differential then the wheels.

#### Specification
| Feature | Details |
|---|---|
| **Voltage** | DC 7.4-12.0 V |
| **Power** | 26 W |
| **Unloaded Speed** | 1000 RPM @ 0.60 A |
| **Maximum Power Point (1)** | Load: 2.3 kg·cm (0.22 N·m)<br>Speed: 780 RPM<br>Power: 17 W<br>Current: 2.5 A |
| **Maximum Power Point (2)** | Load: 5.0 kg·cm (0.5 N·m)<br>Speed: 500 RPM<br>Power: 25.6 W<br>Current: 4.5 A |
| **Plugging Parameter** | 2.3 kg·cm (0.21 N·m) @ 16 A |
| **Gear Ratio** | 20:1 |

---

### Servo: Geekservo 360 2KG from ELECFREAKS
<p align="center">
  
</p>
We use this servo to steer the robot. This servo is compatible with LEGO, making it easy and convenient to build the robot by just putting studs in the hole on the side. We like how you can connect two axles to the dual outputs on this servo so you can power two wheels or gears or mount the servo securely inside articulated limbs and other contraptions. Additionally, the gears inside these servos will **slip** when the blocking load is too high instead of jamming, helping avoid damage to our servo and board. It can be connected to servo pin on the extension board.

#### Specification
| Feature | Details |
|---|---|
| **Rotation** | 360° |
| **Start Voltage** | 2.5 V |
| **Working Voltage** | 3.3 – 6.0 V |
| **Rated Voltage** | 4.8 V |
| **Rated Current** | 70 mA |
| **Maximum Torque** | 1.6 ± 0.2 kg·cm (at 4.8 V) |
| **Angle Rotation Speed**| 60° / 0.14 s |

---

## Power management
### Battery: Firefox 3-cell 11.1v 1300mah from Firefox
<p align="center">
  
</p>
The 11.1V battery enhances the robot's performance by providing higher voltage, which reduces current draw and minimizes power losses during our sessions. This battery ensures stable and continuous functionality without significant voltage drops, even under high current loads, a critical factor during intense practice sessions and competitions. The battery has 1300 mah which is enough to power all of our components. We also uses 2 step down for our robot which will be mentioned later on.

#### Specification
| Feature | Details |
|---|---|
| **Cells** | 3 |
| **Voltage** | 11.1 V |
| **Capacity** | 1300 mAh 20C |
| **Charging Current**  | Up to 5 × capacity (5C) |
| **Connectors** | Dean type, easily disconnectable |

---

### Stepdown: HW316E V6.0.1 and LM2596
Stepdown or Buck converter is very essential to power both Raspberry Pi and motor driver. Step-downs act like a power limiter for the battery. In our robot, we uses 2 different step-down due to the size. 

#### HW316E V6.0.1
<p align="center">
  
</p>
This is the stepdown we use to power our extension board. We set the limit voltage to 10 volts to achive the perfect power for our motor. This stepdown also comes with a display LED to indicate the battery level. It can show both input and the output limit we setted. 

#### LM2596
<p align="center">
  
</p>
We use this step down for Raspberry Pi. The output limit is set to 5 volts otherwise the Raspberry Pi would get short-circuit. It doesn't come with a screen so we need to use multimeter to measure the output although it isn't necessary since we can use the screen on another step down. The wire must be solder into the circuit. On the output end we use a Type-C wire and then connect to the controller.

---

### On-Off Switch
<p align="center">
  
</p>
This switch is for cutting the power from the battery to the robot. The regulation states that before starting the robot, the power must be cut off. That's when this switch came in. To use this switch, we solder red wire (Positive pole) to the switch on 1 side for input. Then another solder red wire for output on the opposite side. You can put the black wire (Negative pole) straight into the step down. When the switch is turned on, the power from the battery will direct into stepdowns and then the Raspberry Pi and Driver board.

---

### Wire Splitter
<p align="center">
  
</p>
To power both the Raspberry Pi and Arduino Nano, we use a wire splitter to divide the battery connection into two wires per pole. For example, the positive pole is split into two separate wires, each directed to the positive input of its own step-down converter. The same is done for the negative pole. This ensures that both boards receive stable and isolated power from the same battery source.

# Wiring Diagram
This diagram will show how to wire and connect every hardware on our robot. 
<p align="center">
  
</p>

## Full Robot Assembly
<p align="center">
  
</p>
This is the real photo of our robot. It consists of every component we listed.

---

# ROS 2 Humble Explanation
In this competition, there are multiple approaches we could use, such as machine learning, ROS, or writing plain code directly on an Arduino board. Since our LiDAR only supports Raspberry Pi, we chose ROS because of its strong ability to handle navigation and decision-making.

There are two generations of ROS:

- **ROS 1 (2010–2025)**
The original Robot Operating System. Its final release, ROS Noetic Ninjemys (2020), will be supported until 2025. After that, it will no longer receive updates, making it unsuitable for long-term projects or competitions.
- **ROS 2 (2017–present)**

The next generation of ROS, designed to overcome ROS 1’s limitations. It adds real-time support, improved communication via DDS middleware, stronger security, and better support for multi-robot systems. ROS 2 is still actively developed with multiple distributions. 

We selected ROS 2 Humble because it is stable, reliable, and has a large support community—perfect for our competition project.

## What is **ROS 2 Humble**?

ROS 2 (Robot Operating System 2) is an open-source framework for building and running robot applications. It provides libraries, tools, and conventions to make developing complex robotic systems easier.

The Humble Hawksbill release, commonly called ROS 2 Humble, is a Long-Term Support (LTS) version released in May 2022, with updates and security patches maintained until May 2027.

Because it is stable and reliable, ROS 2 Humble is widely used in education, research, and industry—making it an ideal choice for long-term projects such as WRO competitions.

## Why **ROS 2 Humble**?

The Future Engineers category challenges the competitors to design autonomous robots that can navigate, sense, and make decisions. ROS 2 is a strong fit because:
- Modular design – Breaks robot software into nodes that can handle tasks like motor control, camera vision, and sensor fusion separately.
-Communication system – Uses topics, services, and actions for real-time data exchange between nodes, which is essential for autonomous navigation.
- Hardware flexibility – Works on Raspberry Pi, NVIDIA Jetson, or PCs, and supports many sensors and actuators.
- Simulation tools – Integrates with Gazebo and RViz to test algorithms before deploying on the physical robot.
- Community & libraries – Many open-source packages (SLAM, navigation, vision, etc.) are available, which saves development time.

## Key Concepts of **ROS 2 Humble**

- Node – A single program that performs a specific task (e.g., controlling a motor, processing camera images).
- Topic – A channel where nodes publish and subscribe to share data (e.g., /camera/image_raw).
- Service – A request/response interaction (e.g., “start motor” or “get distance”).
- Action – Handles longer tasks that can provide feedback and be canceled (e.g., navigation goals).
- Package – A collection of nodes, configuration files, and launch files grouped as one project module.

## Advantages of Using Humble in Competitions

- Stability (LTS) – Reliable platform during multi-year competition cycles.
- Wide hardware support – Works well with microcontrollers (via ROS 2 Micro-ROS), Raspberry Pi, and AI boards.
- Future-proof – We can reuse the same codebase and extend it each season.
- Industry alignment – Skills learned transfer directly to robotics and automation fields.

## Typical ROS 2 Workflow for a WRO Robot

- Perception – Use a camera or sensors → ROS 2 node processes the data.
- Planning – Navigation stack or custom algorithm decides how to move.
- Control – Motor controller node executes wheel commands.
- Testing – Upload the written program to the robot.

## Conclusion
ROS 2 Humble provides a structured, modular, and industry-standard software framework for building autonomous robots. For WRO Future Engineers, it helps teams develop reliable robots that can sense, think, and act both in simulation and in real matches.

# Program Explanation
This part explains our robot program in both Qualification and Final round. We uses ROS2 to communicate between Arduino and Raspberry Pi. The Arduino will act like a motor, light sensor, and servo controller. And then the Raspberry Pi will make decision while communicating with LiDAR, camera, and Arduino. With this setup, it allow us to achive the best decision making robot while remain the fast, accurate, and stable robot.

To use the program, the first thing you need to understand is the concept of a **node**. A node is like a self-contained program that performs a specific task in ROS, such as controlling a motor, reading a sensor, or processing data. In our robot, we have nodes for the **light sensor**, **IMU**, **camera**, **LiDAR**, **button**, and the **main program**. Each node is written separately so it can be run independently or together with other nodes. The second thing you need is a **launch file**, which is used to start multiple nodes at once, for example, starting the camera and LiDAR nodes automatically. You run the launch file from the terminal and then start the **main node**, which acts like the **`setup()` function in Arduino**, initializing the robot and running the main program loop. This structure allows ROS to manage all components efficiently while keeping each part modular and easy to control.

### Light Sensor and Motor/Servo Workflow

Arduino (Light Sensor)  
&nbsp;&nbsp;↓ (send sensor data)  
Raspberry Pi → **Light Sensor Node** (publisher)  
&nbsp;&nbsp;↓ (publish topic)  
**Main Node** (subscriber & decision making)  
&nbsp;&nbsp;↓ (publish motor/servo commands)  
**Arduino Communication Node** (sends commands via USB)  
&nbsp;&nbsp;↓ (receive commands)  
Arduino → **Motor & Servo** (execute movement)

### Raspberry Pi to Arduino Node
This is the main node used to communicate between Pi and Arduino via USB port.
```python
#!/usr/bin/env python3
import rclpy
from rclpy.node import Node
from std_msgs.msg import Int32
import serial
import time
import threading

class ArduinoSerialNode(Node):
    def __init__(self):
        super().__init__("arduino_serial_node")
        
        # Current motor and servo values
        self.current_motor_speed = 0
        self.current_servo_angle = 91  # Center position
        self.last_command_time = time.time()
        
        # Publishers for sensor data from Arduino
        self.light_sensor_pub = self.create_publisher(Int32, "light_sensor", 10)
        
        # Subscribers for commands to Arduino
        self.motor_speed_sub = self.create_subscription(
            Int32, "motor_speed", self.motor_speed_callback, 10
        )
        self.servo_angle_sub = self.create_subscription(
            Int32, "servo_angle", self.servo_angle_callback, 10
        )
        
        # Serial setup
        try:
            self.ser = serial.Serial("/dev/ttyUSB0", 115200, timeout=0.1)
            time.sleep(2)  # Wait for Arduino to reset
            self.get_logger().info("Arduino serial connection established on /dev/ttyUSB0")
        except Exception as e:
            self.get_logger().error(f"Failed to connect to Arduino: {e}")
            self.ser = None
            return
        
        # Timers
        self.read_timer = self.create_timer(0.02, self.read_serial)  # 50 Hz read
        self.send_timer = self.create_timer(0.05, self.send_commands)  # 20 Hz send
        
        # Thread lock for serial communication
        self.serial_lock = threading.Lock()
        
        self.get_logger().info("Arduino Serial Node started")
        self.get_logger().info("Listening for light sensor data and motor/servo commands")

    def motor_speed_callback(self, msg):
        """Handle motor speed commands from controller"""
        self.current_motor_speed = max(0, min(100, msg.data))  # Clamp 0-100
        self.last_command_time = time.time()
        self.get_logger().debug(f"Motor speed updated: {self.current_motor_speed}")

    def servo_angle_callback(self, msg):
        """Handle servo angle commands from controller"""
        self.current_servo_angle = max(67, min(113, msg.data))  # Clamp 67-113
        self.last_command_time = time.time()
        self.get_logger().debug(f"Servo angle updated: {self.current_servo_angle}")

    def send_commands(self):
        """Send motor and servo commands to Arduino"""
        if not self.ser:
            return
        try:
            with self.serial_lock:
                command = f"{self.current_motor_speed},{self.current_servo_angle}\n"
                self.ser.write(command.encode('utf-8'))
        except Exception as e:
            self.get_logger().error(f"Error sending to Arduino: {e}")

    def read_serial(self):
        """Read sensor data from Arduino"""
        if not self.ser:
            return
        try:
            with self.serial_lock:
                while self.ser.in_waiting > 0:
                    line = self.ser.readline().decode(errors="ignore").strip()
                    if line:
                        self.process_arduino_data(line)
        except Exception as e:
            self.get_logger().error(f"Serial read error: {e}")

    def process_arduino_data(self, line):
        """Process incoming data from Arduino"""
        self.get_logger().debug(f"RAW ARDUINO: '{line}'")
        if line.isdigit():
            try:
                light_value = int(line)
                msg = Int32()
                msg.data = light_value
                self.light_sensor_pub.publish(msg)
            except ValueError:
                self.get_logger().warn(f"Invalid light sensor data: '{line}'")
        elif line.startswith("STATUS:"):
            self.get_logger().info(f"Arduino status: {line}")
        elif line.startswith("ERROR:"):
            self.get_logger().error(f"Arduino error: {line}")
        elif line.startswith("READY"):
            self.get_logger().info("Arduino is ready")
        else:
            if len(line) > 0:
                self.get_logger().debug(f"Unknown Arduino data: '{line}'")

    def safety_check(self):
        """Stop motor if no commands received recently"""
        if time.time() - self.last_command_time > 2.0:
            if self.current_motor_speed > 0:
                self.get_logger().warn("No recent commands - stopping motor for safety")
                self.current_motor_speed = 0
                self.current_servo_angle = 91

def main(args=None):
    rclpy.init(args=args)
    node = ArduinoSerialNode()
    if node.ser is None:
        node.get_logger().error("Failed to initialize serial connection. Exiting.")
        return
    try:
        rclpy.spin(node)
    except KeyboardInterrupt:
        node.get_logger().info("Arduino Serial Node shutting down...")
    finally:
        if node.ser:
            try:
                with node.serial_lock:
                    node.ser.write("0,91\n".encode('utf-8'))  # Stop motor, center servo
                    time.sleep(0.1)
                    node.ser.close()
            except:
                pass
        node.destroy_node()
        rclpy.shutdown()

if __name__ == "__main__":
    main() 
```

#### **Explanation**

We use a Python node to connect the Raspberry Pi with the Arduino through the serial port. This node allows ROS to send commands to control the motor and servo, and also receive sensor values back from the Arduino. Commands are sent in the format `MOTOR_SPEED,SERVO_ANGLE`. For example, `50,91` means the motor runs at 50% speed and the servo is set to the center at 91°. The motor speed is limited to a range of 0–100, and the servo angle is limited to 67–113 to prevent damage.

The Arduino also sends data back to ROS, such as light sensor readings, which are published on the `light_sensor` topic. Additionally, the Arduino can send status messages like `READY`, `STATUS:OK`, or `ERROR`, allowing the system to monitor its own state.

To ensure safety, if no command is received for more than 2 seconds, the node will stop the motor and reset the servo to the center position. This prevents the robot from continuing to move unintentionally. The program also ensures that when it shuts down, it always sends `0,91` to safely stop the robot.

In short, this Python node acts as a bridge between ROS 2 and the Arduino. ROS sends motor and servo commands, while the Arduino sends sensor values and status messages back to ROS, allowing the robot to operate safely and reliably.

## Qualification Round

### Main Program (C++)
```C++
#include <Servo.h>

// Motor pins (single motor)
#define motor1A 5
#define motor1B 6

// Servo setup
Servo servo;
const int Steering_Servo = 2;

// Light sensor
const int sensorPin = A7;
int sensorValue = 0;

// Servo limits
const int servoRight = 113;
const int servoLeft = 67;
const int servoMiddle = 91;

// Motor control variables
int currentMotorSpeed = 0;
int currentServoAngle = servoMiddle;

// Timing
unsigned long lastSensorRead = 0;
unsigned long lastCommandTime = 0;
const unsigned long COMMAND_TIMEOUT = 1000; // 1 second timeout

void setup() {
  Serial.begin(115200);
  
  // Initialize motor pins (single motor)
  pinMode(motor1A, OUTPUT);
  pinMode(motor1B, OUTPUT);
  
  // Initialize servo
  servo.attach(Steering_Servo, 500, 2500);
  servo.write(servoMiddle);
  
  // Stop motor initially
  motor(1, 0);
  
  Serial.println("READY");
  delay(100);
}

void loop() {
  // 1. READ COMMANDS from ROS
  readROSCommands();
  
  // 2. SEND LIGHT SENSOR DATA to ROS (every 20ms = 50Hz)
  if (millis() - lastSensorRead >= 20) {
    sensorValue = analogRead(sensorPin);
    Serial.println(sensorValue);
    lastSensorRead = millis();
  }
  
  // 3. SAFETY CHECK - stop if no commands received
  if (millis() - lastCommandTime > COMMAND_TIMEOUT && currentMotorSpeed > 0) {
    Serial.println("ERROR: Command timeout - stopping motor");
    currentMotorSpeed = 0;
    currentServoAngle = servoMiddle;
    applyMotorCommands();
  }
  
  delay(5);
}

void readROSCommands() {
  if (Serial.available()) {
    String command = Serial.readStringUntil('\n');
    command.trim();
    
    // Parse "motor_speed,servo_angle" format
    int commaIndex = command.indexOf(',');
    if (commaIndex > 0) {
      int motorSpeed = command.substring(0, commaIndex).toInt();
      int servoAngle = command.substring(commaIndex + 1).toInt();
      
      // Validate and apply commands
      if (motorSpeed >= 0 && motorSpeed <= 100 && 
          servoAngle >= servoLeft && servoAngle <= servoRight) {
        
        currentMotorSpeed = motorSpeed;
        currentServoAngle = servoAngle;
        lastCommandTime = millis();
        
        applyMotorCommands();
        
        // Debug output (comment out for production)
        // Serial.print("STATUS: Motor=");
        // Serial.print(currentMotorSpeed);
        // Serial.print(", Servo=");
        // Serial.println(currentServoAngle);
      } else {
        Serial.print("ERROR: Invalid command - Motor:");
        Serial.print(motorSpeed);
        Serial.print(", Servo:");
        Serial.println(servoAngle);
      }
    } else {
      Serial.print("ERROR: Invalid format - ");
      Serial.println(command);
    }
  }
}

void applyMotorCommands() {
  // Apply servo angle
  servo.write(currentServoAngle);
  
  // Apply motor speed using your motor function
  motor(1, currentMotorSpeed);
}

// Your motor control function
void motor(int motorNumber, int speed) {
  if (motorNumber == 1) {
    if (speed == 0) {
      // Stop motor
      analogWrite(motor1A, 0);
      analogWrite(motor1B, 0);
    } else {
      // Convert 1-100 speed to PWM (0-255)
      int pwmValue = map(speed, 1, 100, 50, 255); // Minimum 50 for reliable start
      
      // Drive motor forward (adjust direction based on your wiring)
      analogWrite(motor1A, pwmValue);
      analogWrite(motor1B, 0);
    }
  }
}
```

#### **Explanation**
This is a program written in C++ in order to control the robot. It uses the Arduino as the muscle and Raspberry Pi as a main. When the program start, the arduino will take place in controlling the robot whether it's steering or driving. The Arduino will also read the light sensor input so that it can detect the lines on the track. The light sensor will send the detected input to ROS2. Then the ROS 2 will respond back with the data to control the motor and servo, in the meanwhile it will also collaborate with LiDAR and gyro in order to ensure that the robot would stay in the middle. And in case that the arduino doesn't receive the information from Raspberry Pi, the robot would stop and servo will return to it's middle position. And there are a few functions to explain.

##### **Void readROSCommands**
```C++
void readROSCommands() {
  if (Serial.available()) {
    String command = Serial.readStringUntil('\n');
    command.trim();
    
    // Parse "motor_speed,servo_angle" format
    int commaIndex = command.indexOf(',');
    if (commaIndex > 0) {
      int motorSpeed = command.substring(0, commaIndex).toInt();
      int servoAngle = command.substring(commaIndex + 1).toInt();
      
      // Validate and apply commands
      if (motorSpeed >= 0 && motorSpeed <= 100 && 
          servoAngle >= servoLeft && servoAngle <= servoRight) {
        
        currentMotorSpeed = motorSpeed;
        currentServoAngle = servoAngle;
        lastCommandTime = millis();
        
        applyMotorCommands();
        
        // Debug output (comment out for production)
        // Serial.print("STATUS: Motor=");
        // Serial.print(currentMotorSpeed);
        // Serial.print(", Servo=");
        // Serial.println(currentServoAngle);
      } else {
        Serial.print("ERROR: Invalid command - Motor:");
        Serial.print(motorSpeed);
        Serial.print(", Servo:");
        Serial.println(servoAngle);
      }
    } else {
      Serial.print("ERROR: Invalid format - ");
      Serial.println(command);
    }
  }
}
```
The `void readROSCommands` function is used to handle communication between ROS and the Arduino via the serial port. It receives commands containing motor speed and servo angle. The function first checks if there is any serial input. If data is available, it reads the line until it encounters a newline character (`\n`) and removes any extra spaces using `trim()`. It expects the command in the format `MOTOR_SPEED,SERVO_ANGLE` and converts these values into integers.  

Next, it validates the values: the motor speed must be between 0 and 100, and the servo angle must be within the allowed range, defined as left = 67°, middle = 91°, and right = 113°. If the values are valid, the function updates the current motor speed and servo angle, records the time the command was received, and calls `applyMotorCommands()` to apply the command to the hardware.  

If the command is invalid, the function sends an error message back over serial to notify the user. In summary, this function acts as a bridge between ROS and Arduino, ensuring that only valid motor and servo commands are applied.

**This is the workflow**

```
+-----------------------------+
| ROS (motor & servo command) |
+-------------+---------------+
|
▼
+-----------------+
| Serial port (USB)|
+--------+--------+
|
▼
+-------------------+
| readROSCommands() |
+--------+----------+
|
| - Checks if serial data is available
| - Reads line until '\n' and trims whitespace
| - Splits command into motor speed & servo angle
| - Validates motor (0-100) and servo (67-113)
▼
+--------+
| Valid? |
+---+----+
|
+-------+-------+
| |
▼ ▼
Yes No
| |
▼ ▼
Updates currentMotorSpeed & currentServoAngle
|
▼
+------------------------+
| applyMotorCommands() |
| Sends signals to motor |
| & servo |
+------------------------+
```

##### **void applyMotorCommands**
```c++
void applyMotorCommands() {
  // Apply servo angle
  servo.write(currentServoAngle);
  
  // Apply motor speed using your motor function
  motor(1, currentMotorSpeed);
}
```
The `void applyMotorCommands` function is responsible for sending the updated motor and servo values to the hardware itself. First, it sets the servo to the current angle by calling `servo.write(currentServoAngle)`, which physically moves the steering servo to the desired position. Then, it applies the motor speed by calling the `motor()` function with the motor number (in this case `1`) and the current motor speed (`currentMotorSpeed`).  

In summary, this function takes the latest validated values from ROS or other sources and directly updates the servo and motor hardware, making the robot move and steer according to the commands.

##### **void motor**
```c++
void motor(int motorNumber, int speed) {
  if (motorNumber == 1) {
    if (speed == 0) {
      // Stop motor
      analogWrite(motor1A, 0);
      analogWrite(motor1B, 0);
    } else {
      // Convert 1-100 speed to PWM (0-255)
      int pwmValue = map(speed, 1, 100, 50, 255); // Minimum 50 for reliable start
      
      // Drive motor forward (adjust direction based on your wiring)
      analogWrite(motor1A, pwmValue);
      analogWrite(motor1B, 0);
    }
  }
}
```
The `void motor` function controls the motor speed, identified by `motorNumber`. In this case, it handles motor number 1. If the `speed` is 0, the function stops the motor by setting both motor pins (`motor1A` and `motor1B`) to 0 using `analogWrite`.  

If the `speed` is greater than 0, it converts the 1–100 speed range into a PWM value between 50 and 255 using the `map()` function. The minimum value of 50 ensures the motor starts reliably. Then, it drives the motor forward by sending the PWM signal to `motor1A` while keeping `motor1B` at 0.  

In short, this function translates a high-level speed command into a PWM signal to control the motor’s rotation safely and reliably.

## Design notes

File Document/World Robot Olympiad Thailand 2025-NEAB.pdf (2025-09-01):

# World Robot Olympiad Thailand 2025

# Future Engineers Categories Documentation

# YB-NEAB

# Content

# 1. About Our Team

# 2. Engineering Consideration

# 3. Chassis Design and Robot Photos

# 4. Hardware Information

# 5. ROS 2 Humble Explanation

# 1. About Our Team

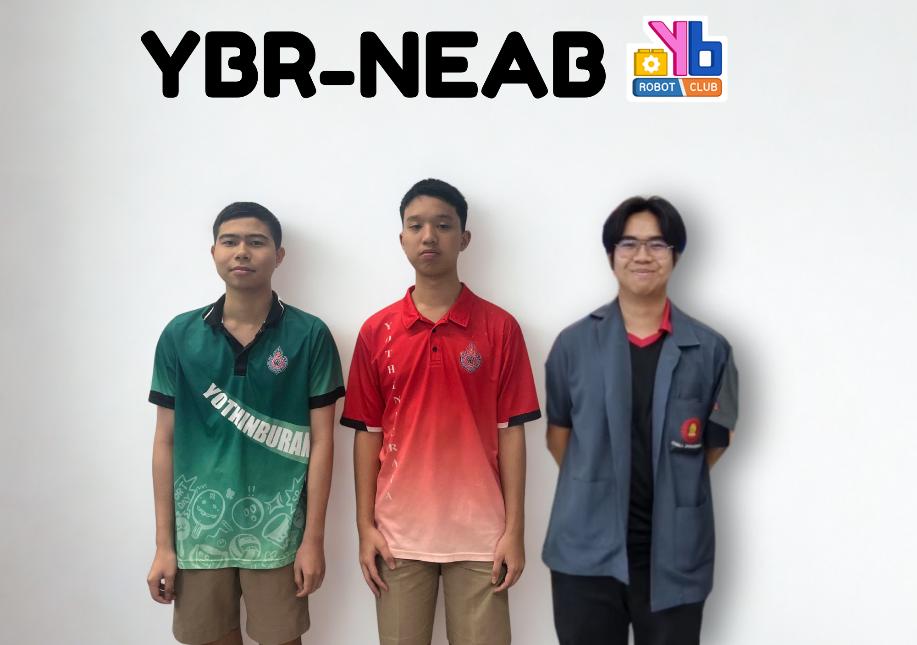
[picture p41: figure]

Our team consists of three members;

# each assigned a different role:

1. Vichaiwat Koonsap – I am responsible for gathering data for our team members and taking detailed notes, which are then compiled into this documentation. I'm the on the middle.
2. Norrapat Kesthong – Norrapat is responsible for designing and building our robot. He's on the right side.
3. Vorawet Narkglom – Vorawet is the programmer who coded the robot. He stands on the left side.

# 2. Engineering Consideration

During the design process of our robot, we faced several engineering challenges, particularly in translating real-world measurements into our 3D modeling software. After printing, we frequently encountered issues with small features—for example, a M3 screw thread could not be printed accurately caused by 3d printer's nozzle size, resulting in undersized holes. This showed the importance of accounting for 3D printer limitations during the design stage. Paying close attention to these details helps minimize

unnecessary redesigns and reprints.

Another key learning was the importance of incorporating a differential system. At first, we placed gears of equal size next to each other, but this setup proved ineffective. By integrating a differential, the wheels were able to rotate at different speeds—an essential factor for smooth turning and overall

robot performance.

### The robot chassis was modeled in Fusion 360 and manufactured using FDM 3D printing. This approach provided durability, lightweight construction, and effective protection for the onboard hardware. The design was fully

customized by our mechanic to meet the specific needs of our robot.

# Our robot aim and objective

## 1. Innovation and Creativity:

### -Encourage participants to design and build innovative robots that

can perform complex tasks.

### -Promote creative thinking and the development of unique solutions

to the given challenges.

## 2. Engineering Skills:

-Enhance participant’s engineering skills through the design, construction, and programming of advanced robots.

### -Foster an understanding of mechanical design, electronics, and

software integration in robotics.

## 3. Problem-Solving:

-Challenge participants to solve real-world problems using robotics, requiring analytical thinking and strategic planning.

### -Develop participants' ability to troubleshoot and optimize their

robotic systems.

## 4. Collaboration and Teamwork:

-Promote collaboration and effective teamwork among participants.

### -Encourage communication and cooperation within teams to achieve

common goals.

## 5. Application of STEM Knowledge:

### -Apply theoretical STEM knowledge to practical scenarios, reinforcing

learning through hands-on experience.

### -Integrate multiple STEM disciplines to develop comprehensive robotic

solutions.

## 6. Presentation and Documentation:

### -Develop participants' skills in presenting their projects and solutions

effectively.

### -Emphasize the importance of thorough documentation, including the

design process, programming, and testing.

# Robot Photos

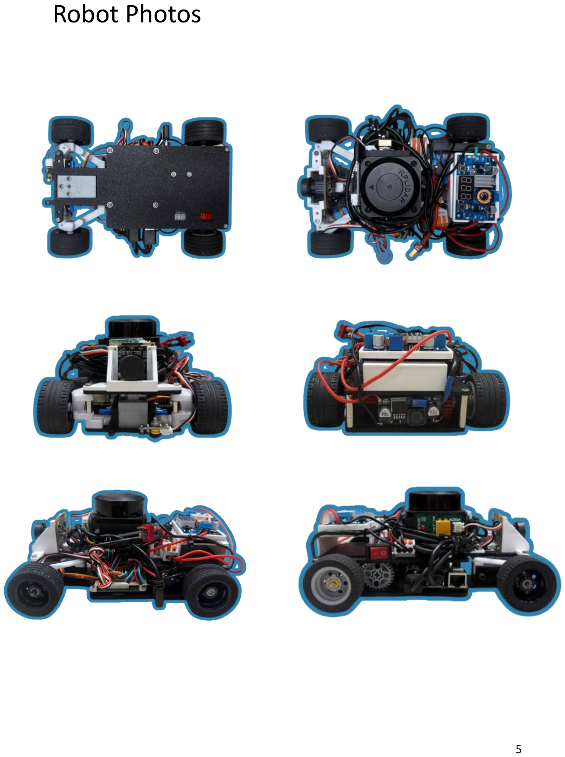
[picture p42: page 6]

# 3. Chassis Design

# 3.1 3D Printer and Filament

## Bambu Lab P1S Combo

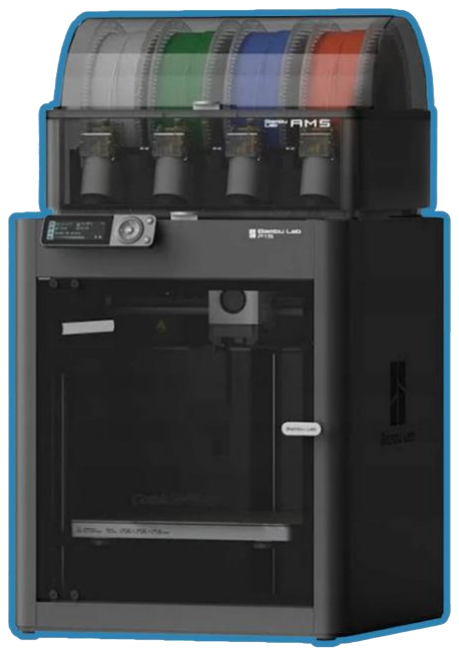
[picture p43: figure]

This is our 3D printer, which we use to produce both prototypes and the final robot chassis. It is capable of high-speed printing without compromising quality or risking failure. The printer features a fully enclosed chamber, allowing safe printing of high-temperature or hazardous materials such as ABS and ASA. It is one of Bambu Lab’s best-selling models.

Additionally, it comes with an Automated Material System (AMS), enabling the printer to handle up to four different materials—whether the same or different types of plastic. The AMS also includes an Auto Reload function, allowing us to print overnight without worrying about filament running out.

## Specification

Feature | Details
Model | P1S Combo
Build Volume | 256 × 256 × 256 mm³
Print Speed | Up to 500 mm/s
Acceleration | Up to 20,000 mm/s²
Extruder Type | Direct Drive
Nozzle Type | Stainless Steel (upgradeable to hardened steel)
Hotend Max Temp | 280°C (supports high-temp filaments with upgraded nozzle)
Heatbed Max Temp | 100°C
Enclosure | Fully enclosed with carbon filter and fans
Cooling System | Auxiliary part cooling fan, chamber regulator fan, control board fan
AMS Compatibility | Yes (supports up to 16-color multi-material printing)
Connectivity | Wi-Fi, USB, Bambu-Bus
Display | 2.7-inch 192×64 screen
Software | Bambu Studio (supports Cura, PrusaSlicer, SuperSlicer)
Camera | Built-in for remote monitoring and time-lapse
Dimensions (WxDxH) | 389 × 389 × 458 mm³
Weight | 9.5 kg
Power Input | 100–240 VAC, 50/60 Hz
Max Power Consumption | 1000 W @ 220V, 350 W @ 110V

## Polylactic Acid or PLA

PLA is the most common filament used in 3D printing. It is easy to print, produces minimal stringing, and requires relatively low printing temperatures. However, it also has some drawbacks: it cannot withstand high heat and is more brittle compared to other materials. Because of this, we use PLA for thin parts that need to remain lightweight while still providing support without bending.

For our robot, we selected Sunlu PLA+ 2.0, an enhanced

version of standard PLA. This material is stronger, lighter, and more flexible, giving us the benefits of PLA while improving durability and performance.

## Polyethylene Terephthalate Glycol or PETG

PETG is another popular 3D printing filament, valued for its flexibility, strength, chemical resistance, and ability to withstand higher temperatures than PLA. Its main drawbacks are increased stringing and a slightly rougher surface finish.
Because PETG is highly impact-resistant, we use it for components that are more likely to experience collisions, ensuring the robot remains intact even after repeated impacts.

For our robot, we selected Polymaker PolyLite PETG. Polymaker is a trusted brand known for its consistency and reliability, with minimal defects. This PETG is particularly user-friendly, offering printability close to that of PLA while maintaining the toughness needed for demanding parts.

# 3.2 Printed Robot Chassis

All the 3D printable models can be found here. (https://github.com/Snackels/NEAB/tree/main/3D%20models)

## Lower Base

The lower base serves as the foundation of our robot, supporting nearly all essential components: the controller, motors, steering servo, light sensors, buck converter, and differential.

When designing this part, precise measurements were critical to ensure a proper fit for each component. In our robot, we uses a LEGO TECHNIC parts like axle, differential, and gear to ensure that those part would not
break during our sessions.

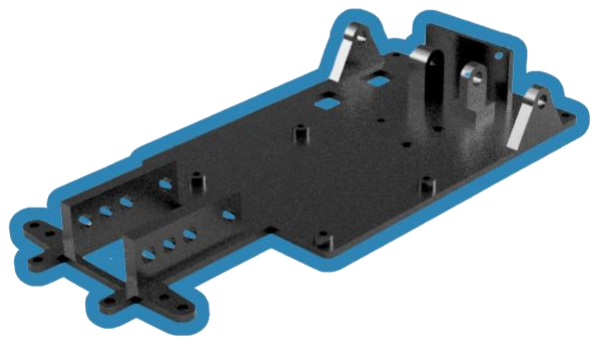
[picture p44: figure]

To secure the LEGO axle, we designed support poles at the back of the base to hold it firmly in place. With this design, it allows the robot to reach its full potential.

## Upper Base

The upper base is positioned 3 cm above the lower base and is designed to hold the remaining components while providing additional stability to the robot.

To ensure a clean and seamless build, we applied the counterbore technique so that screws do not interfere with the lower section. This approach allowed us to hide the

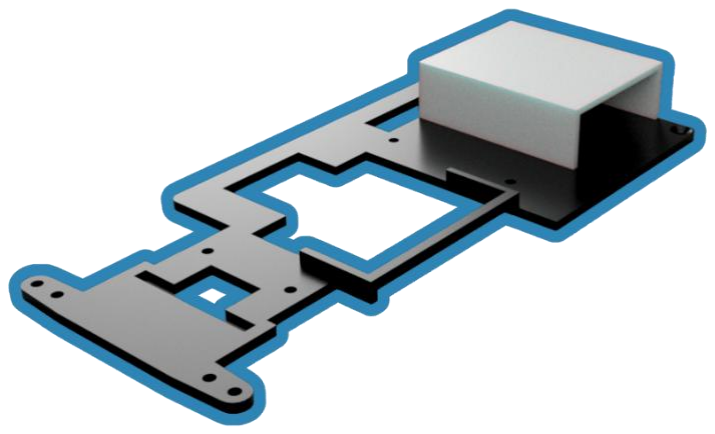
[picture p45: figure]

screws neatly, giving the chassis a screwless appearance.

Additionally, the upper base includes a battery slot at the back, ensuring secure placement and easy accessibility during operation.

### Arduino Nano Riser

Since we are using the Arduino Nano, we needed to find an ideal place to place it. The perfect location is right on top of the Raspberry Pi, allowing both boards to stay compact and organized. To achieve this, we designed the setup to use the same M2.5 screws that secure the Raspberry Pi. We also carefully accounted for the position of the GPIO pins and all necessary wiring, ensuring that everything fits neatly without interfering with connections.

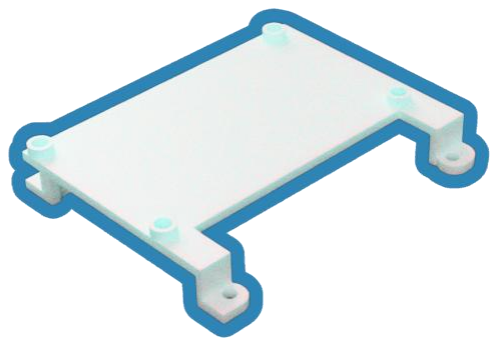
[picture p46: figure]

### LiDAR Holder

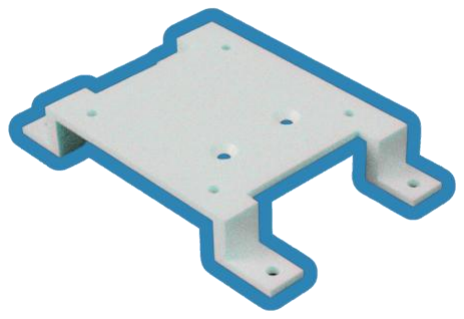
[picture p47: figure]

The LiDAR holder is mounted on top of the upper base to keep the LiDAR elevated above other components. This prevents the sensor from mistakenly detecting parts of the robot itself.

The holder also included a slot for the gyro sensor, positioned directly beneath the LiDAR. This compact arrangement minimizes the overall robot size while ensuring that the LiDAR remains within the 10 cm height limit to avoid detecting over the wall.

### Camera mount

This component serves as a **stand for the camera** and includes protective covers for both the front and top.
The design serves two key purposes:

Protection – In case of collisions with walls, the front cover acts as a guard to protect the camera lens from damage.

Vision Control – The top cover blocks external light and distractions, ensuring the camera only captures the track area.

This combination enhances both the durability and reliability of the vision system during sessions.

### Motor Bracket

It holds the motor with the lower base. This design offer us a small, effective, and strong bracket. With 3 screw holes for attaching it to the base and 2 screw holes for attaching it to motor. This part also uses the Counterbore technique.

### Gear Adapter

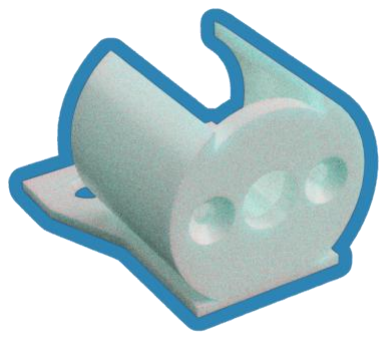
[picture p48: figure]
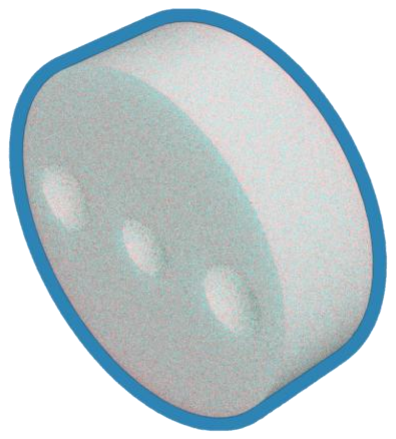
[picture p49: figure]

The gear we used was from **LEGO Technic**. Meaning that we can't attach it directly to the motor. We designed this part to place it on motor's rotating axle. Then, we added two LEGO pins to attach it to the gear.

### Step-Down Case

The step-down comes with a lot of pin under it. This was caused by soldering. This case was made to make sure that the bottom stays flat and avoid current leakage.

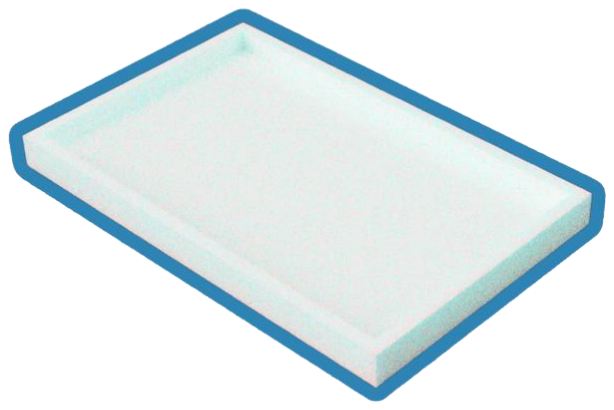
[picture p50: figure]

### Steering Module

It consists of three main components: the servo link, main connector, and wheel bracket. When our mechanic
designed this part, careful
consideration was given to the
steering angle. We applied the Ackermann Steering Principle, a system developed to achieve tighter and more efficient turns. With this method, the inner wheel turns at a sharper angle than the outer wheel—similar to the steering system used in Formula 1 cars. We also ensured that, during turns, the wheels would not collide with the robot’s body.

# 3.3 LEGO Technic Parts

### Differential

This differential includes a 28-tooth double bevel gear, identical to the one used with our motor. Inside, it contains five small gears that allow the opposite wheel to rotate freely. This mechanism ensures that both wheels rotate at the correct speed, even when the robot is turning.

### Gear

We selected a 28-tooth double bevel gear to prevent the robot from losing speed or torque. It is made of ABS plastic, providing durability, and matches the size of the differential.

### Pin

These pins are used to secure the servo to the robot. They act as a lock, ensuring the servo stays firmly in place.

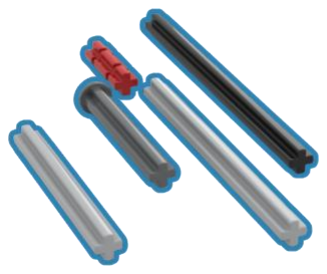
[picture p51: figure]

### Axle

Axles connect the wheels to the robot. We designed a 5.1 mm hole for the axle, allowing it to sit securely while still rotating freely.

### Wheel: 43.2 * 22

The wheel is a crucial component of our robot and comes in various sizes and shapes. We selected this size for its ability to maintain grip on the surface during high-speed turns. Its 43.2 diameter also makes the robot easy to control.

### Half Bush

This component creates space between the wheel and the robot, ensuring that the wheels can rotate freely without being obstructed during operation.

# 3.4 Additional

### Screws

Screws come in various sizes. We designed our robot primarily around M3 screws, as they are the most common in robotics. In some cases, such as mounting the Raspberry Pi or LiDAR, M2.5 screws are required. For our build, we mainly use countersunk screws. To accommodate them, we chamfered the M3 screw holes by 1.8 mm, creating the perfect countersunk fit that allows the screws to sit flush and remain neatly hidden.

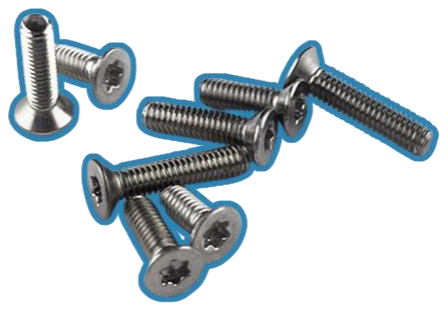
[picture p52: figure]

M3 Countersunk Screws

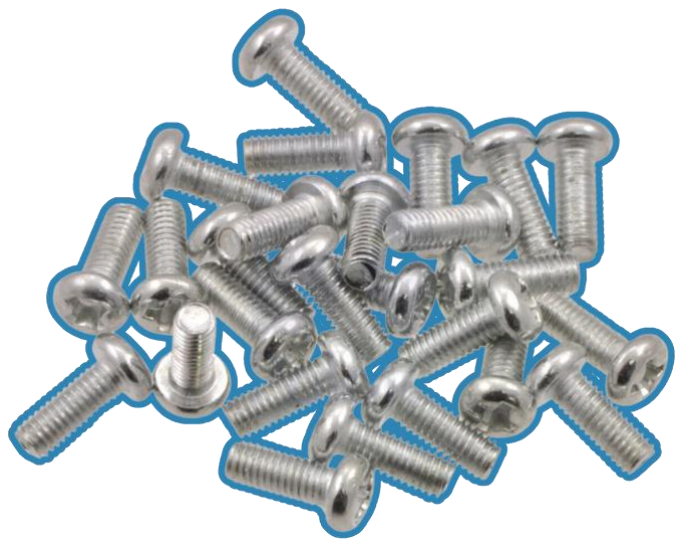
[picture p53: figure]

M2.5 Screws

### PCB Support Post

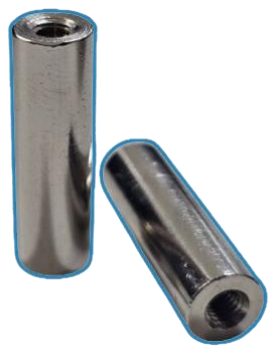
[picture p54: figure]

The support posts connect the first and second floors of the robot. They enhance stability, ensuring that the LiDAR and camera remain steady during operation.

# 3.5 Design References

### Counterbore Technique

Counterbore and countersunk are two techniques used to make screws sit flush with a surface. A countersunk hole has an angled top, allowing cone-shaped screws to fit
neatly inside and create a smooth finish, while a
counterbore hole has a flat, widened top so cylindrical screw heads can sit below the

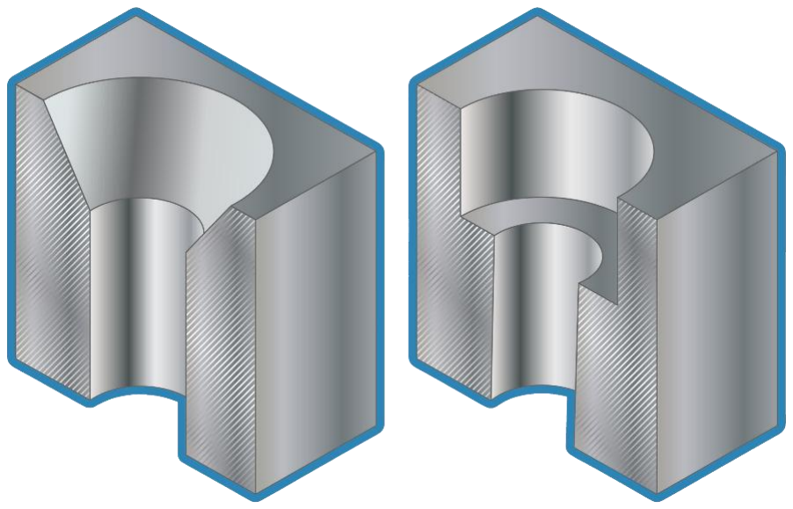
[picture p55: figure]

surface. In our robot, we use these methods to merge the screw into the structure by chamfering 1.8 mm into the screw hole or creating a 4 mm wide hole with a 2 mm depth. This not only saves space but also gives the robot a cleaner and more professional look.

Ackerman Steering

Ackermann steering is a method where the inner wheel turns sharper than the outer wheel when the robot turns. This matches the natural path of the wheels, preventing them from sliding against the ground. It makes the robot easier to control, gives it a tighter turning radius, and reduces friction—just like in real cars and F1 racing.

# 3.6 Printing Process

To print this robot, we first use a slicer to generate the **G-code for the 3D printer. In our case, we use Bambu Studio. A slicer lets us set up a print profile, which defines whether the part will be strong, lightweight, or have a smooth surface. Once the profile is set, we check for overhangs — parts of the model that “float” without support. While printers can handle small overhangs, larger ones require supports. Supports are temporary structures that hold the object during printing and can be removed afterward. There are two main types: normal supports and tree supports, with tree supports being the most popular because they use less filament and print faster. After preparing everything, we start the print.

Here’s a timelapse of the printing process for some of our parts:

# 3.7 Full Chassis Assembly

This is what our robot looks like with all the chassis part combined.

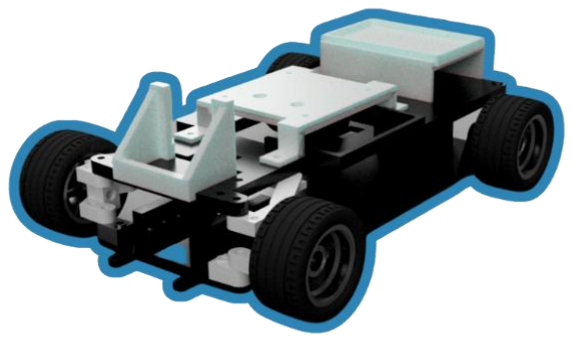
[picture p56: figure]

# 4. Hardware Information

# 4.1 Controller

### Main controller: Raspberry Pi 4 Model B from Raspberry Pi

The Raspberry Pi 4 Model B was the first component we selected, and it serves as the most crucial part of the robot, acting as the brain of the system. Without it, the robot cannot process information or make decisions. The Raspberry Pi is widely used as a controller due to its versatility and accessibility, functioning like a mini computer with 4 USB ports, 40 GPIO pins,

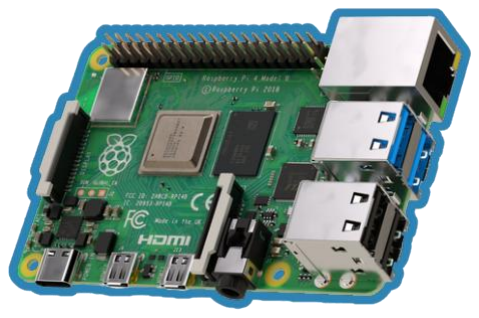
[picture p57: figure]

and dedicated slots for a camera and monitor. It can be powered via a USB-C connector with an operating voltage of 5 volts. Since we chose ROS2 as the robot’s operating system, the Raspberry Pi 4 was the ideal choice to handle the required computation and communication tasks. And it can be connected with Wi-Fi or LAN cable for communicating with the programming computer.

Specification

Feature | Details
Processor | Broadcom BCM2711, Quad core Cortex-A72 (ARM v8) 64-bit SoC @ 1.8GHz
Memory Options | 1GB, 2GB, 4GB or 8GB LPDDR4-3200 SDRAM
Wireless | 2.4 GHz and 5.0 GHz IEEE 802.11ac, Bluetooth 5.0, BLE
Ethernet | Gigabit Ethernet
USB Ports | 2 × USB 3.0, 2 × USB 2.0

Feature | Details
GPIO | 40-pin header (fully backwards compatible)
Display Output | 2 × micro-HDMI® (up to 4kp60), 2-lane MIPI DSI
Camera Interface | 2-lane MIPI CSI port
Audio/Video | 4-pole stereo audio and composite video port
Video Support | H.265 (4kp60 decode), H.264 (1080p60 decode, 1080p30 encode)
Graphics | OpenGL ES 3.1, Vulkan 1.0
Storage | Micro-SD card slot (OS and data storage)
Power Input | 5V DC via USB-C (min 3A), 5V DC via GPIO (min 3A), Power over Ethernet (PoE with HAT)
Operating Temperature | 0 – 50 °C ambient

Extension Board: Arduino Nano from Princebot

Using a Raspberry Pi comes with some limitations. Its GPIO pins only provide digital signals, meaning it cannot directly control motors or servos, and it also lacks built-in support for analog readings. To solve this, we use an extension board. The Arduino Nano is a small, fast, and flexible microcontroller, making it an ideal choice. By pairing the Nano with a custom PCB, we can easily drive motors, control servos, and read data from analog sensors. The PCB

supports up to 10 volts of battery input, which makes it the perfect fit for our robot components.

Specification

Feature | Details
Processor | Atmega328 (Arduino Nano)
Input Voltage | 6–10 V (with reverse polarity protection)
Motor Driver | 2 × modules (6–10 V, 1.5 A each)
Sensor Ports | 6 × Analog (JST connectors)
Servo Ports | 6 × Digital (servo compatible)
Buzzer | 1 × Speaker
Switches | 1 × Switch (D12), 1 × Reset switch
Dimensions | 64 mm (W) × 45 mm (H)

# 4.2 Sensors and visibility

### LiDAR: RPLIDAR C1 from SLAMTEC

This is a LiDAR, a device that emitted light toward the surface and then measure the time it take to bounce back. Most of the car uses it for parking. This part plays a crucial role in this competition, by measuring the distance between the inner and outer wall then divide by 2 so that the robot would stay in the perfect middle. And it also plays a significant role in parking sequence due to it's ability to view 360 degree. We can connect the LiDAR with the USB port on Raspberry Pi, making it very user friendly.

Specification

Feature | Details
Distance Range | White object: 0.05–12 m (70% reflectivity) Black object: 0.05–6 m (10% reflectivity)
Sample Rate | 5 kHz
Scanning Frequency | 8–12 Hz (10 Hz typical)
Angular Resolution | 0.72° (typical)
Scan Field Flatness | 0°–1.5°
Communication Interface | TTL UART
Communication Speed | 460800 baud
Accuracy | ±30 mm
Resolution | 15 mm

Feature | Details
Degree of Protection | IP54
Ambient Light Limit | 40,000 lux
Weight | 110 g
Working Temperature | -10 °C to +40 °C
Storage Temperature | -20 °C to +60 °C

### Camera: HBV-1716WA

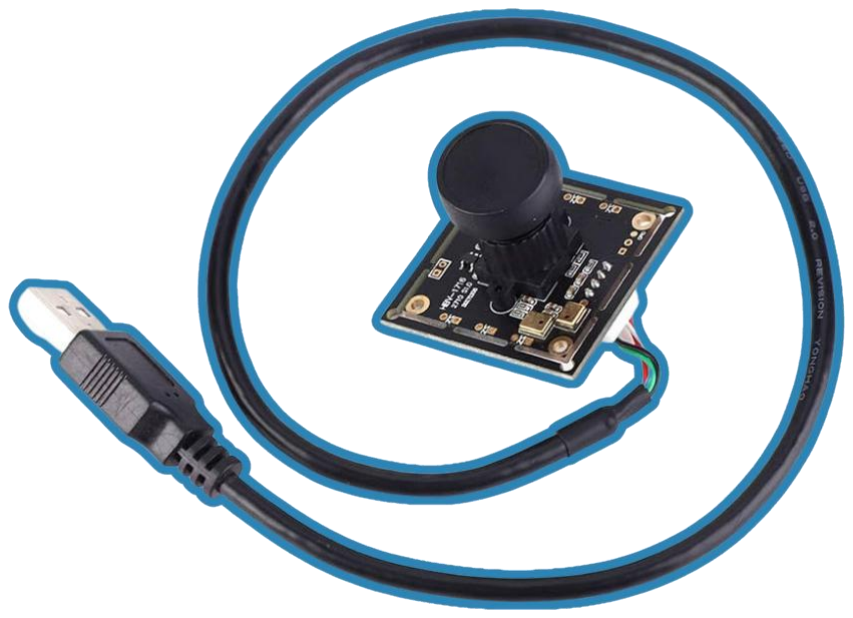
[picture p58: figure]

This component is very important for avoiding obstacle. It can detect red and green obstacle from distance to avoid crashing into it. It can co-operate with the LiDAR to ensure the maximum efficiency when the robot turns to avoid the block. This camera doesn't have it's own micro-controller meaning that it can achive it's full **frame per sec** performance. And it can also be connect to Raspberry Pi through USB port.

Specification

Feature | Details
Model | HBV-1716WA
Highest Resolution | 1920 × 1080
Field of View | 140°
Chip | OV2710 (1/2.7")
Frame Per Second | 30 FPS
Weight | Approx. 32 g / 1.1 oz
Outer Size | Approx. 38 × 38 × 25 mm / 1.5 × 1.5 × 1.0 in
Inner Size | Approx. 32 × 32 × 25 mm / 1.3 × 1.3 × 1.0 in

### Gyro Sensor: SEN-0253 from DFRobot

Gyro sensor is a component that enables a robot to determine its orientation and turn in the appropriate direction. The gyro sensors detect 3 axis: yaw, pitch, and roll. We chose this gyro sensor specifically because of how effective it is. It collaborate with LiDAR and camera to ensure that the robot would not steer of it's course when it's turning to avoid the obstacle. And it
also helps when the robot initiate the parking. It helps
the robot make sure that it is turning toward the right

direction. The gyro uses I2C wiring. The I2C features 4 different wire: SDA, SCL, 5 volts, and Ground. The wires go onto the GPIO pins on Raspberry Pi.

Specification

Feature | Details
Operating Voltage | 3.3 V – 5 V DC
Operating Current | 5 mA
Interface | Gravity-I2C
Operating Temperature | -40 ~ +80 °C
Product Dimension | 32 × 27 mm / 1.26 × 1.06”

BNO055 Accelerometer

Feature | Details
Acceleration Ranges | ±2 g / ±4 g / ±8 g / ±16 g
Low-pass Filter Bandwidth | 1 kHz ~ <8 Hz

Feature | Details
Operation Modes | Normal, Suspend, Low Power, Standby, Deep Suspend
Interrupt Control | Motion-triggered interrupt signal

BNO055 Gyroscope

Feature | Details
Ranges | ±125°/s ~ 2000°/s (switchable)
Low-pass Filter Bandwidth | 523 Hz ~ 12 Hz
Operation Modes | Normal, Fast Power Up, Deep Suspend, Suspend, Advanced Power Save
Interrupt Control | Motion-triggered interrupt signal

BNO055 Geomagnetic

Feature | Details
Magnetic Field Range | ±1300 μT (x-, y-axis), ±2500 μT (z-axis)
Magnetic Field Resolution | ~0.3
Operating Modes | Low Power, Regular, Enhanced Regular, High Accuracy
Power Modes | Normal, Sleep, Suspend, Force

BMP280 Digital Pressure Sensor

Feature | Details
Pressure Range | 300 ~ 1100 hPa
Relative Accuracy | ±0.12 hPa (~ ±1 m)
Absolute Accuracy | ±1 hPa (~ ±8.33 m)
Temperature Range | 0 °C ~ 65 °C
Temperature Resolution | 0.01 °C

### Reflected Light Sensors: TC-01 from Princebot

Reflected Light Sensors come in various color. Each color can be used for different surface color. This track has 3 different colors: red, blue, and white. We tried using a single red or blue light, but it doesn't work. So at first we come up with using 2 sensors at the same time. And in the end, we settle on using a single **White light** color. White has an ability to amazingly seperate the red, blue, and white. It's purpose is to count and detect lines. This sensor uses **JST** head as a connector. Since our extension board also uses JSTs, we can connect the sensor

straight to it.

### Touch Sensor: ZX-Switch from INEX

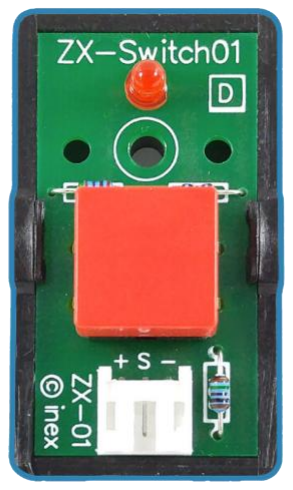
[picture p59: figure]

This button gives us an easier way to start the robot. Since the controller board doesn't come with switches. So, we found this button that could be attached to the frame outside the board using bolt. It gives us the advantages, when we start the robot we can turn on the switch and then keep the robot on the ground so that it would have time to reset it's gyro and other components. Then we press the switch to start and stop the robot. This sensor required a digital reading. The input would be 0 and 1. 1 being pressed and 0 being nothing. We wired this straight into Raspberry Pi's GPIO pins.

# 4.3 Driving and Steering

### Motor: GM25-370 from Chihai Motor

This motor is usually used for a sumo robot due to it's speed and power. We then uses this with our robot because it can help us achive the speed we need to win this competition. And since our robot is very heavy due to the various components, this motor comes in real handy. We uses this motor with extension board to control the speed and the power it uses. The rotating axis

is connected to a gear which then transfer the spinning to a differential then the wheels.

Specification

Feature | Details
Voltage | DC 7.4-12.0 V
Power | 26 W
Unloaded Speed | 1000 RPM @ 0.60 A
Maximum Power Point (1) | Load: 2.3 kg·cm (0.22 N·m) Speed: 780 RPM Power: 17 W Current: 2.5 A
Maximum Power Point (2) | Load: 5.0 kg·cm (0.5 N·m) Speed: 500 RPM Power: 25.6 W Current: 4.5 A
Plugging Parameter | 2.3 kg·cm (0.21 N·m) @ 16 A
Gear Ratio | 20:1

### Servo: Geekservo 360 2KG from ELECFREAKS

We use this servo to steer the robot. This servo is compatible with LEGO, making it easy and convenient to build the robot by just putting studs in the hole on the side. We like how you can connect two axles to the dual outputs on this servo so you can power two wheels or gears or mount the servo securely inside articulated limbs and other contraptions. Additionally, the gears inside these servos will **slip** when the blocking load is too high instead of jamming, helping avoid damage to our servo and board. It can be connected to servo pin on the extension board.

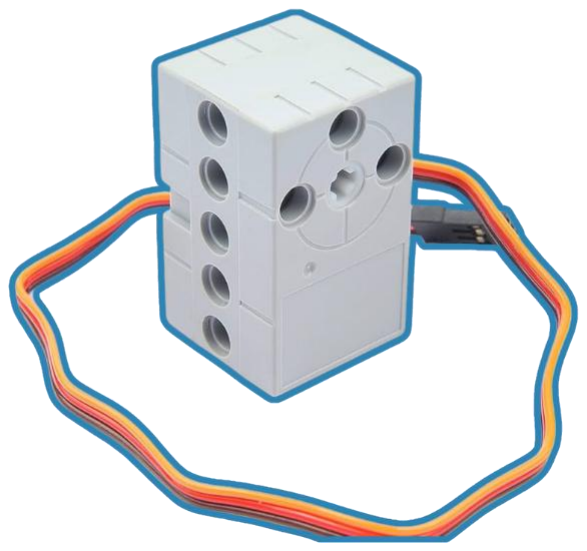
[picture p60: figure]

Specification

Feature | Details
Rotation | 360°
Start Voltage | 2.5 V
Working Voltage | 3.3 – 6.0 V
Rated Voltage | 4.8 V
Rated Current | 70 mA
Maximum Torque | 1.6 ± 0.2 kg·cm (at 4.8 V)
Angle Rotation Speed | 60° / 0.14 s

# 4.4 Power management

### Battery: Firefox 3-cell 11.1v 1300mah from Firefox

The 11.1V battery enhances the robot's performance by providing higher voltage, which reduces current draw and minimizes power losses during our sessions. This battery ensures stable and continuous functionality without significant voltage drops, even under high current loads, a critical factor during intense practice sessions and

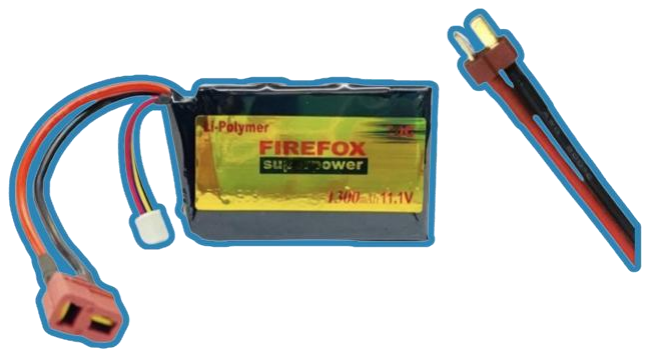
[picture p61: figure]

competitions. The battery has 1300 mah which is enough to power all of our components. We also uses 2 step down for our robot which will be mentioned later on.

Specification

Feature | Details
Cells | 3
Voltage | 11.1 V
Capacity | 1300 mAh 20C
Charging Current | Up to 5 × capacity (5C)
Connectors | Dean type, easily disconnectable

### Stepdown: HW316E V6.0.1 and LM2596

Stepdown or Buck converter is very essential to power both Raspberry Pi and motor driver. Step-downs act like a power limiter for the battery. In our robot, we uses 2 different step-down due to the size.

HW316E V6.0.1

This is the stepdown we use to power our extension board. We set the limit voltage to 10 volts to achive the perfect power for our motor. This stepdown also comes with a display LED to indicate the battery level. It can show both input and the output limit we setted.

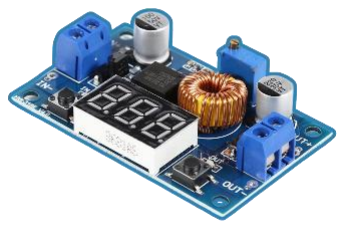
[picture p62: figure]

LM2596

We use this step down for Raspberry Pi. The output limit is set to 5 volts otherwise the Raspberry Pi would get short-circuit. It doesn't come with a screen so we need to use multimeter to measure the output although it isn't necessary since we can use the screen on another step down. The wire must be solder into the circuit. On the output end we use a Type-C wire and then connect to the controller.

### On-Off Switch

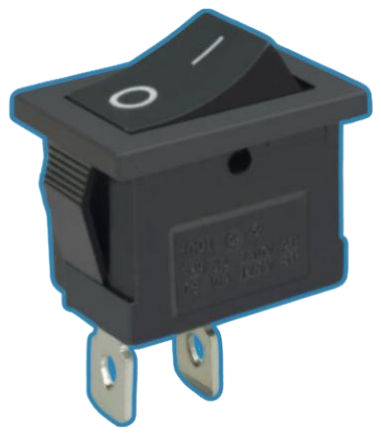
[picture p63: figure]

This switch is for cutting the power from the battery to the robot. The regulation states that before starting the robot, the power must be cut off. That's when this switch came in. To use this switch, we solder red wire (Positive pole) to the switch on 1 side for input. Then another solder red wire for output on the opposite side. You can put the black wire (Negative pole) straight into the step down. When the switch is turned on, the power from the battery will direct into stepdowns and then the Raspberry Pi and Driver board.

Wire Splitter

To power both the Raspberry Pi and Arduino Nano, we use a wire splitter to divide the battery connection into two wires per pole. For example, the positive pole is split into two separate wires, each directed to the positive input of its own step-down converter. The same is done for the negative pole. This ensures that both boards receive stable and isolated power from the same battery source.

# Full Robot Assembly

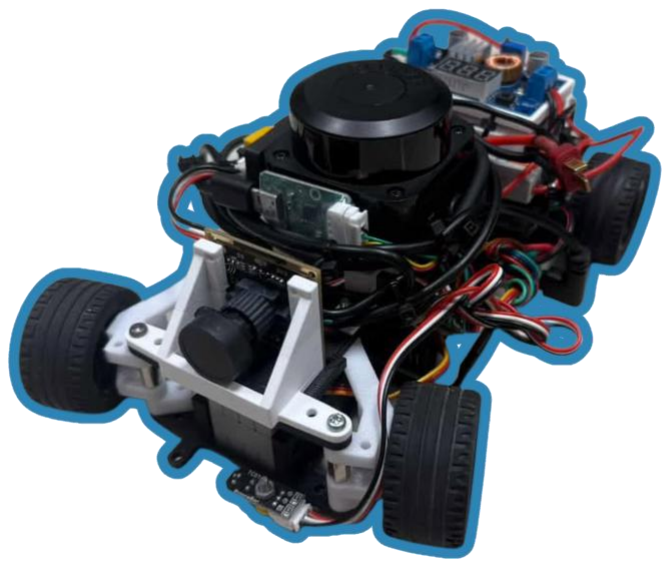
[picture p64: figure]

This is the real photo of our robot. It consists of every component we listed.

# 5.ROS 2 Humble Explanation

In this competition, there are multiple approaches we could use, such as machine learning, ROS, or writing plain code directly on an Arduino board. Since our LiDAR only supports Raspberry Pi, we chose ROS because of its strong ability to handle navigation and decision-making.

There are two generations of ROS:

- ROS 1 (2010–2025) The original Robot Operating System. Its final release, ROS Noetic Ninjemys (2020), will be supported until 2025. After that, it will no longer receive updates, making it unsuitable for long-term projects or competitions.
- ROS 2 (2017–present)

The next generation of ROS, designed to overcome ROS 1’s limitations. It adds real-time support, improved communication via DDS middleware, stronger security, and better support for multi-robot systems. ROS 2 is still actively developed with multiple distributions.

We selected ROS 2 Humble because it is stable, reliable, and has a large support community—perfect for our competition project.

# What is ROS 2 Humble?

ROS 2 (Robot Operating System 2) is an open-source framework for building and running robot applications. It provides libraries, tools, and conventions to make developing complex robotic systems easier.

The Humble Hawksbill release, commonly called ROS 2 Humble, is a Long-Term Support (LTS) version released in May 2022, with updates and security patches maintained until May 2027.

Because it is stable and reliable, ROS 2 Humble is widely used in education, research, and industry—making it an ideal choice for long-term projects such as WRO competitions.

# Why ROS 2 Humble?

The Future Engineers category challenges the competitors to design autonomous robots that can navigate, sense, and make decisions. ROS 2 is a strong fit because:

- Modular design – Breaks robot software into nodes that can handle tasks like motor control, camera vision, and sensor fusion separately. -Communication system – Uses topics, services, and actions for real-time data exchange between nodes, which is essential for autonomous navigation.
- Hardware flexibility – Works on Raspberry Pi, NVIDIA Jetson, or PCs, and supports many sensors and actuators.
- Simulation tools – Integrates with Gazebo and RViz to test algorithms before deploying on the physical robot.
- Community & libraries – Many open-source packages (SLAM, navigation, vision, etc.) are available, which saves development time.

# Key Concepts of ROS 2 Humble

- Node – A single program that performs a specific task (e.g., controlling a motor, processing camera images).
- Topic – A channel where nodes publish and subscribe to share data (e.g., /camera/image_raw).
- Service – A request/response interaction (e.g., “start motor” or “get distance”).
- Action – Handles longer tasks that can provide feedback and be canceled (e.g., navigation goals).
- Package – A collection of nodes, configuration files, and launch files grouped as one project module.

# Advantages of Using Humble in Competitions

- Stability (LTS) – Reliable platform during multi-year competition cycles.
- Wide hardware support – Works well with microcontrollers (via ROS 2 Micro-ROS), Raspberry Pi, and AI boards.
- Future-proof – We can reuse the same codebase and extend it each season.
- Industry alignment – Skills learned transfer directly to robotics and automation fields.

# Typical ROS 2 Workflow for a WRO Robot

- Perception – Use a camera or sensors → ROS 2 node processes the data.
- Planning – Navigation stack or custom algorithm decides how to move.
- Control – Motor controller node executes wheel commands.
- Testing – Upload the written program to the robot.

# Conclusion

ROS 2 Humble provides a structured, modular, and industry-standard software framework for building autonomous robots. For WRO Future Engineers, it helps teams develop reliable robots that can sense, think, and act both in simulation and in real matches.

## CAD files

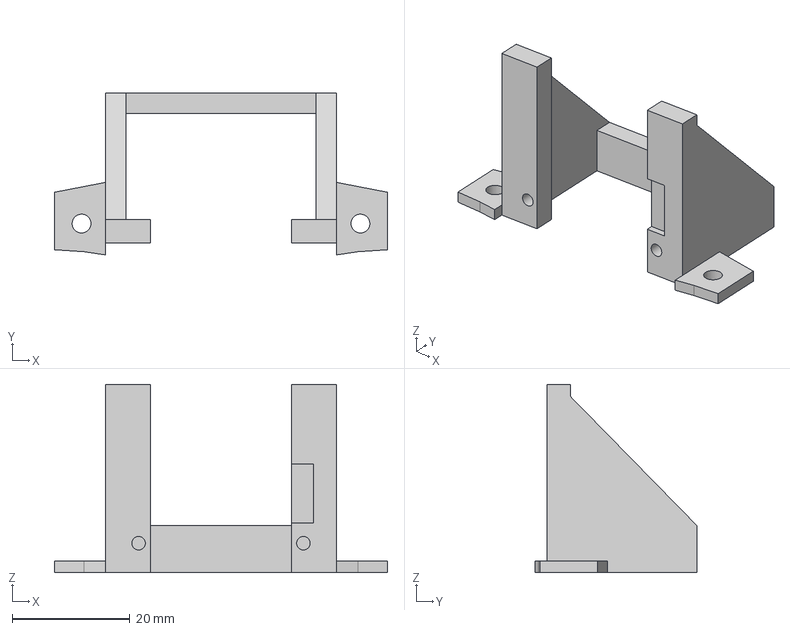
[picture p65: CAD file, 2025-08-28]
3D models/Camera mount.step
56.6 x 27.5 x 32.0 mm

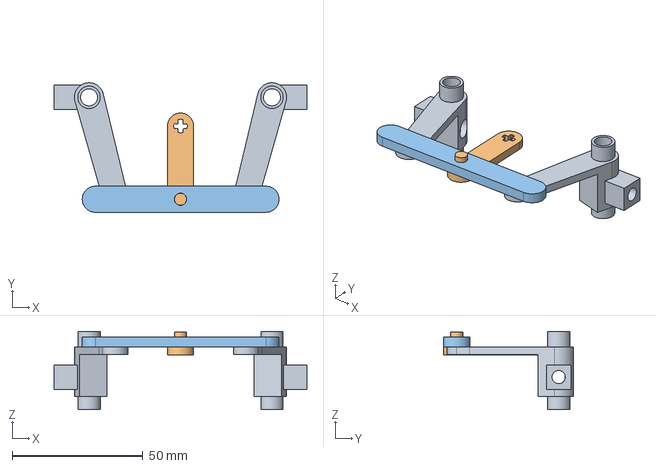
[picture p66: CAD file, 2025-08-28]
3D models/Steering Module.step
96.8 x 49.6 x 30.0 mm

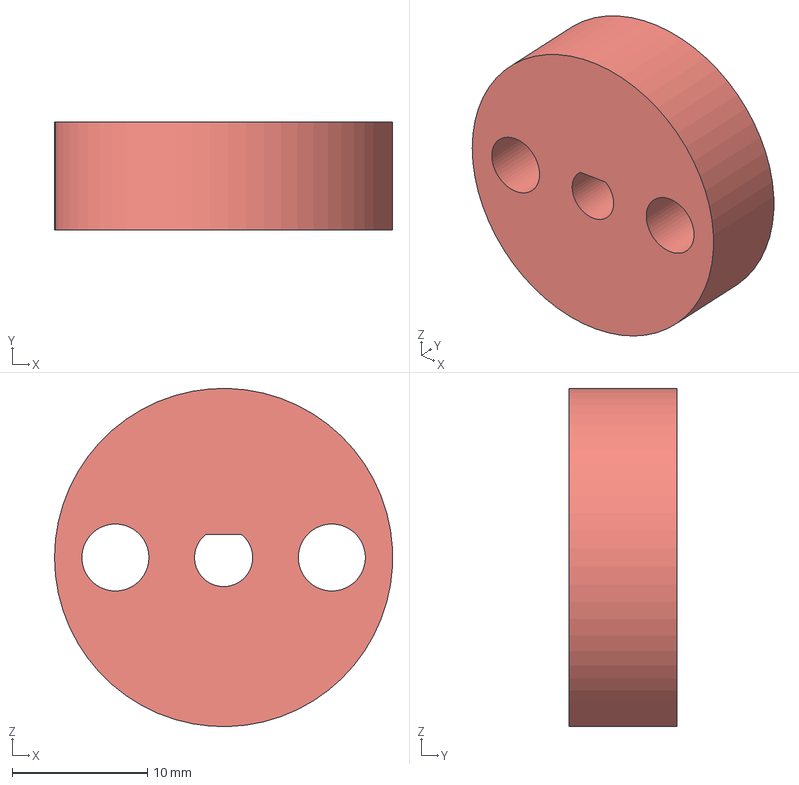
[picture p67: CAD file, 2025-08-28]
3D models/Gear Adapter.step
25.0 x 8.00 x 25.0 mm

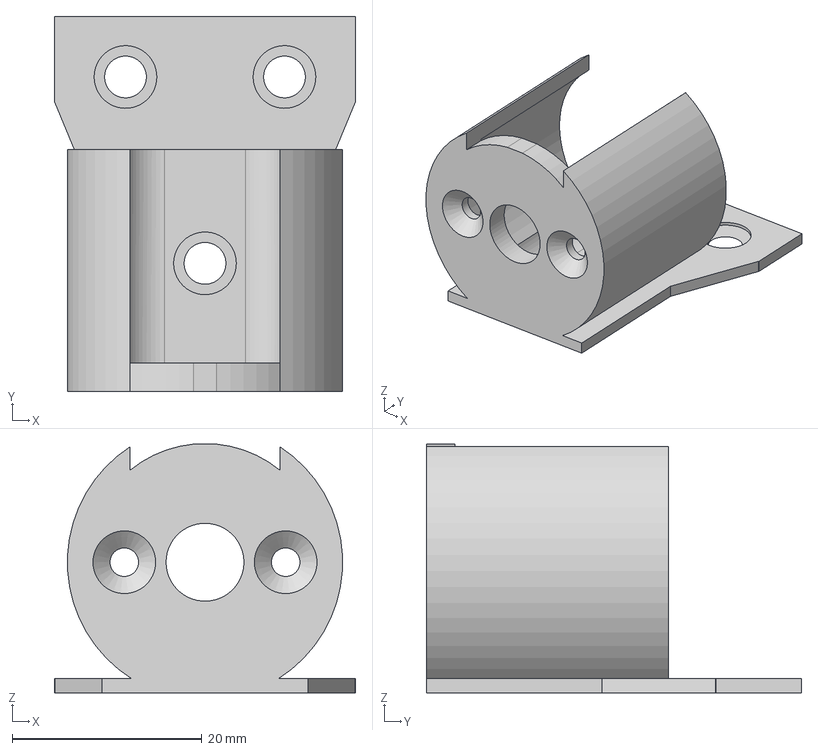
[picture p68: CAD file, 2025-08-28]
3D models/Motor Bracket.step
31.7 x 39.5 x 26.2 mm

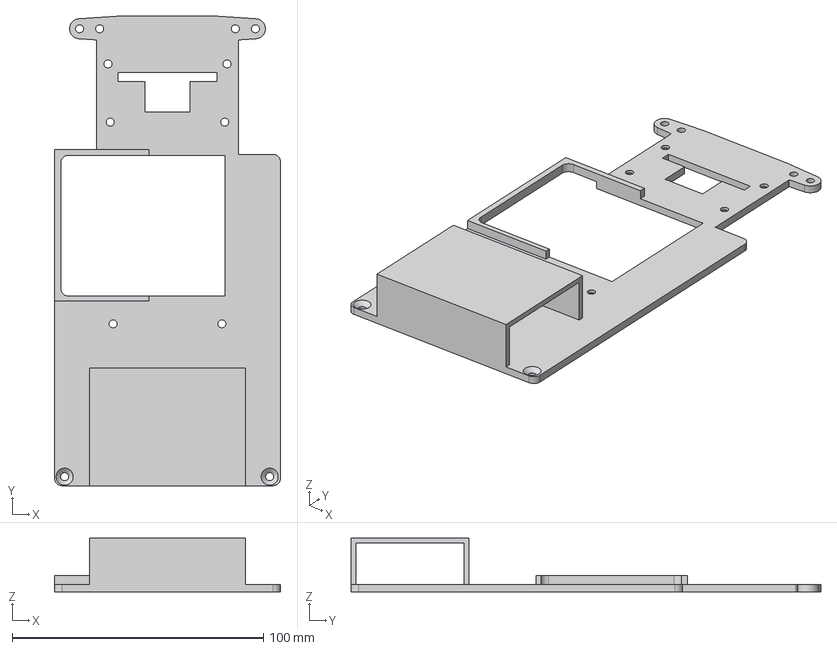
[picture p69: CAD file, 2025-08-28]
3D models/Upper Base.step
90.0 x 187.0 x 21.5 mm

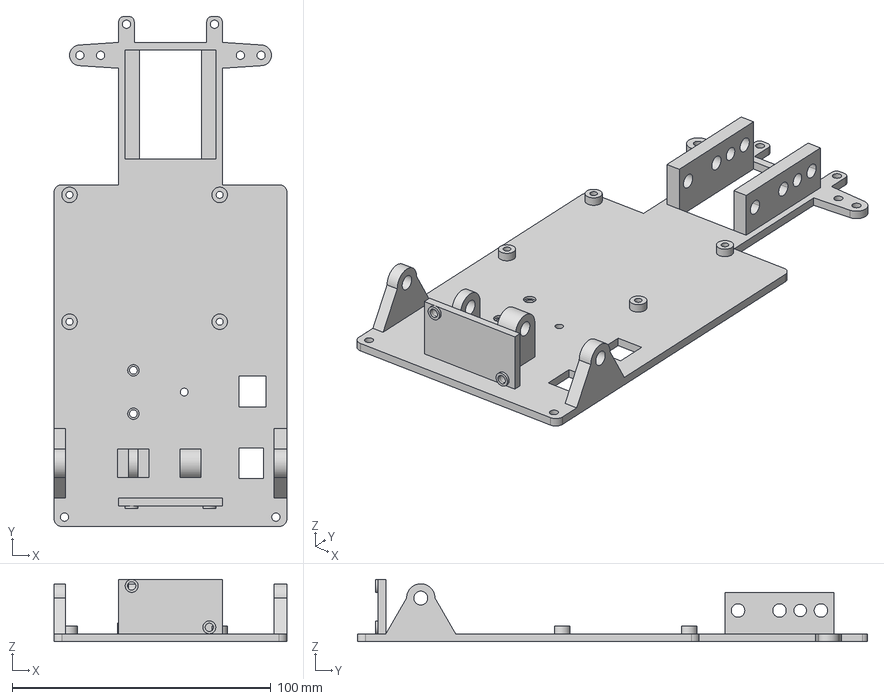
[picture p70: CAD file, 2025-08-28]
3D models/Lower Base.step
90.0 x 197.0 x 24.0 mm

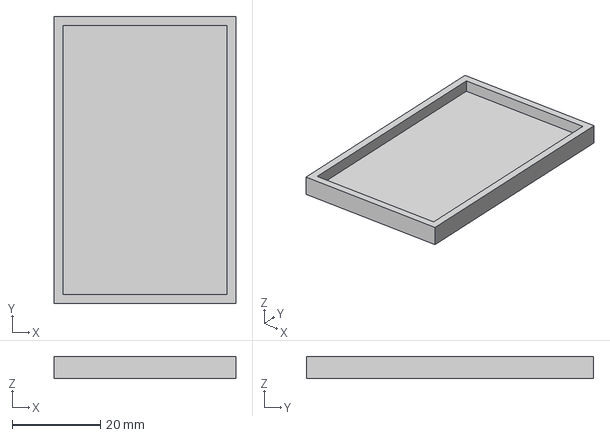
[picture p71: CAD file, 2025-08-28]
3D models/Step-Down Case.step
41.2 x 65.0 x 5.00 mm

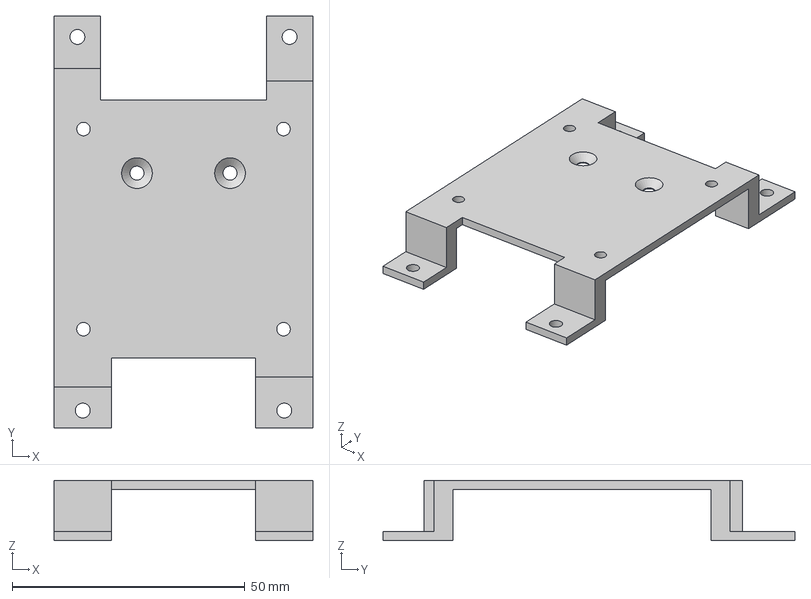
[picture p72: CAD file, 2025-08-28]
3D models/LiDAR Holder.step
55.6 x 88.5 x 13.0 mm

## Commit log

2025-08-25 Printed Robot parts
2025-08-27 Adjust LiDAR
2025-08-27 Added Gyro
2025-08-28 Create Chassis Photos
2025-09-02 Create Diagram and circuit
